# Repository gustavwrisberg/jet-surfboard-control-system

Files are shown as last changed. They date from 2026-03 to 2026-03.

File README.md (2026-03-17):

# Jet-Driven Surfboard Control System

## Project Overview
This project is a **jet-driven surfboard control system** inspired by commercial boards.  
It integrates embedded controllers, wireless communication, and a high-power propulsion system.

### Components Built
- **Controller:** ESP32-based throttle input with OLED display (SS495A Hall sensor)
- **Bridge:** ESP32 VESC bridge for UART communication to VESC and telemetry relay
- **VESC Motor Controller:** Off-the-shelf Makerbase VESC 84V 200A
- **Battery Pack:** Custom 10s5p Li-ion (Enpower INR21700-30SG)
- **Wireless Charging Pad:** For 3.7V cells powering the controller

> Most components are off-the-shelf to reduce cost and accelerate prototyping.  

---

## System Architecture

**Description:**
- Controller reads throttle from Hall sensor and displays telemetry on OLED.
- Throttle is sent to VESC bridge via ESP-NOW.
- VESC bridge communicates throttle to VESC via UART and relays telemetry back to controller.
- Battery supplies power to VESC and controller; wireless charger charges 3.7V cells for the controller.

---

### Wiring Diagram
Wiring Diagram

**Highlights:**
- Color-coded wires for clarity:
  - **Red:** Power lines
  - **Black:** Ground
  - **Blue:** Signal lines
  - **Green:** Communication (UART/ESP-NOW)
- Proper spacing to illustrate connections clearly between Controller, Bridge, VESC, Motor, and Battery.

---

## Build & Flash
Build & Flash Instructions
Install Arduino IDE or PlatformIO.
Install dependencies:
- Adafruit_SSD1306
- Adafruit_GFX
- ESP32 board definitions
Connect ESP32 to your PC.
run the read mac adress simulator, and write that into the code of the opposite controller.

Open controller.ino or bridge.ino.
Select the correct board (ESP32 Dev Module) and COM port.
Click Upload.

## Code Reference
### Controller (Throttle + OLED)
```cpp
// See src/controller.ino
#include <esp_now.h>
#include <WiFi.h>
#include <Wire.h>
#include <Adafruit_GFX.h>
#include <Adafruit_SSD1306.h>
// ... full controller code ...

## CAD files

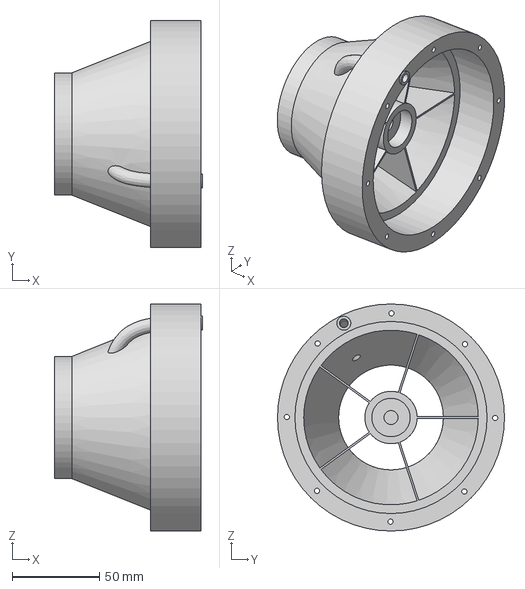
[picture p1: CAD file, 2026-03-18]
3dfiles/Nozzle.step
85.0 x 130.0 x 130.0 mm

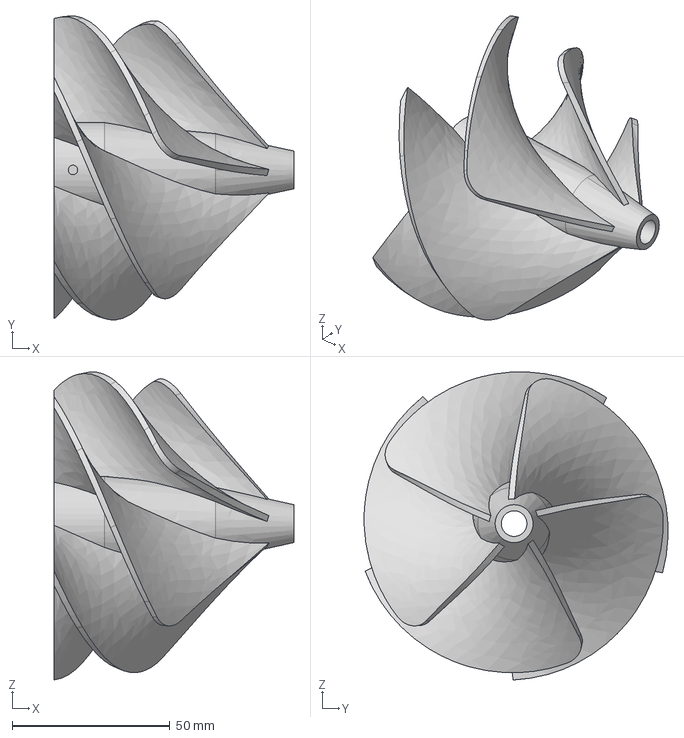
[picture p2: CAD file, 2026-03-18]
3dfiles/Impellar.step
76.0 x 96.3 x 97.6 mm

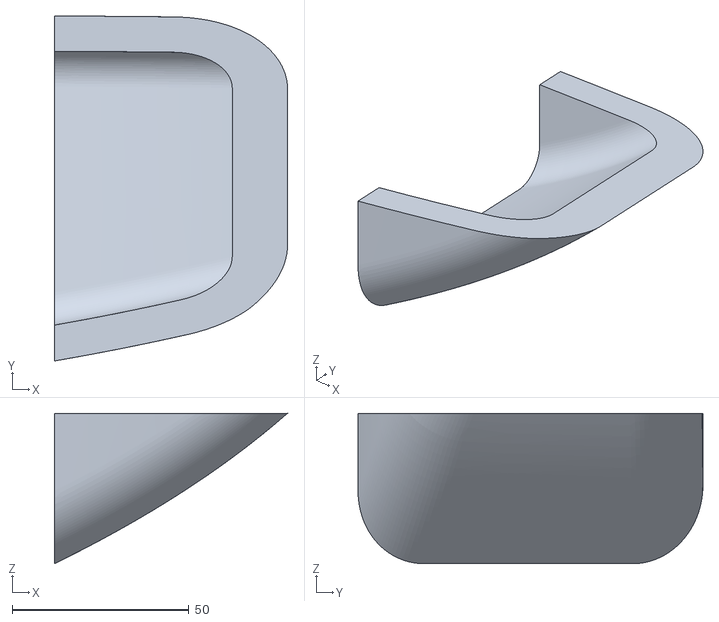
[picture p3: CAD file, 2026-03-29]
3dfiles/Surfboard/Surfboard.stl
66.0 x 97.7 x 42.6

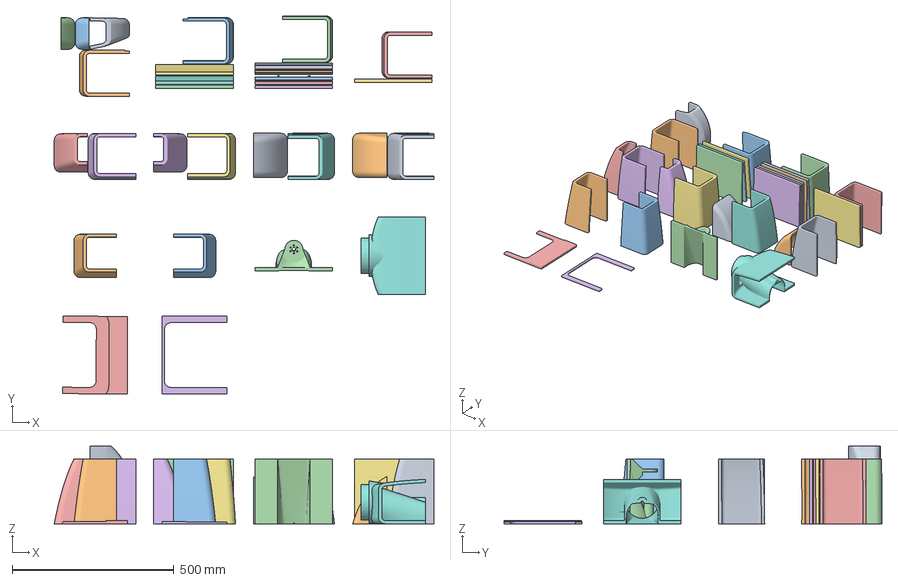
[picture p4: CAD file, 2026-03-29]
3dfiles/Surfboard/Surfboard bambu_lab.3mf
1173.8 x 1169.1 x 240.0 mm
Surfboard (9).stl
Surfboard (2).stl
Surfboard (2) (1).stl
Surfboard (7).stl
Surfboard (7) (1).stl
Surfboard (6) (1).stl
Surfboard (6).stl
Surfboard (5) (1).stl
Surfboard (5).stl
Surfboard (3) (1).stl
Surfboard (3).stl
Surfboard (5) (2).stl
Surfboard (1) (1).stl
Surfboard (1).stl
Surfboard (1) (2).stl
Surfboard (3) (2).stl
Surfboard (6) (3).stl
Surfboard (5) (3).stl
Surfboard (2) (2).stl
Surfboard (1) (3).stl
Surfboard (3) (3).stl
Surfboard (7) (3).stl
Surfboard (6) (2).stl
Surfboard (4) (2).stl
Surfboard (4) (1).stl
Surfboard (4).stl
Surfboard (8).stl
Surfboard.stl
Surfboard (7) (2).stl
Surfboard (2) (3).stl

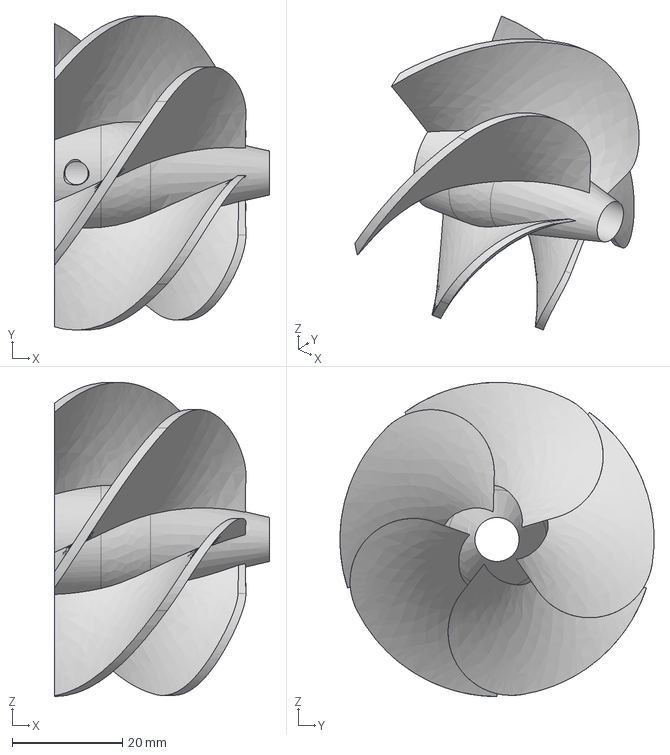
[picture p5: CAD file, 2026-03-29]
3dfiles/Surfboard/small_impellar.step
39.0 x 57.0 x 57.0 mm

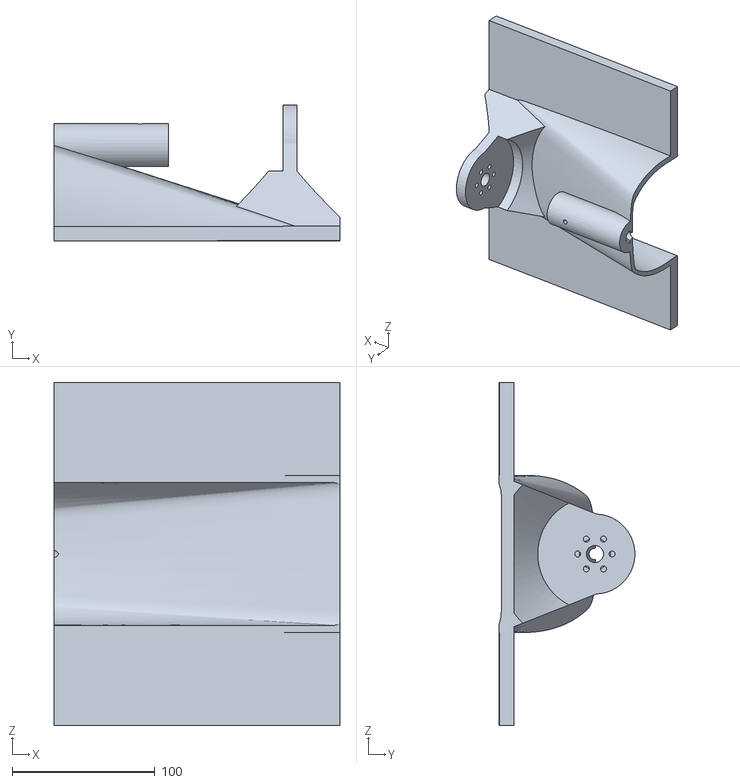
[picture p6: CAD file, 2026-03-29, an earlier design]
3dfiles/Surfboard/Surfboard (5) (2).stl
200.0 x 94.9 x 240.0

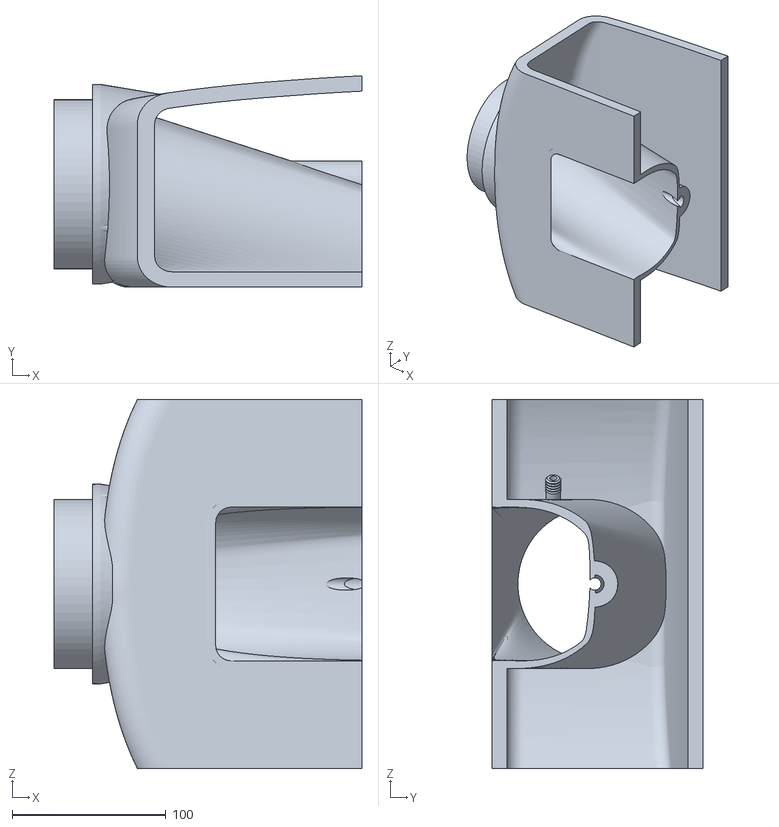
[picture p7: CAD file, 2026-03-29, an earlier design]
3dfiles/Surfboard/Surfboard (4) (2).stl
200.0 x 137.5 x 240.0

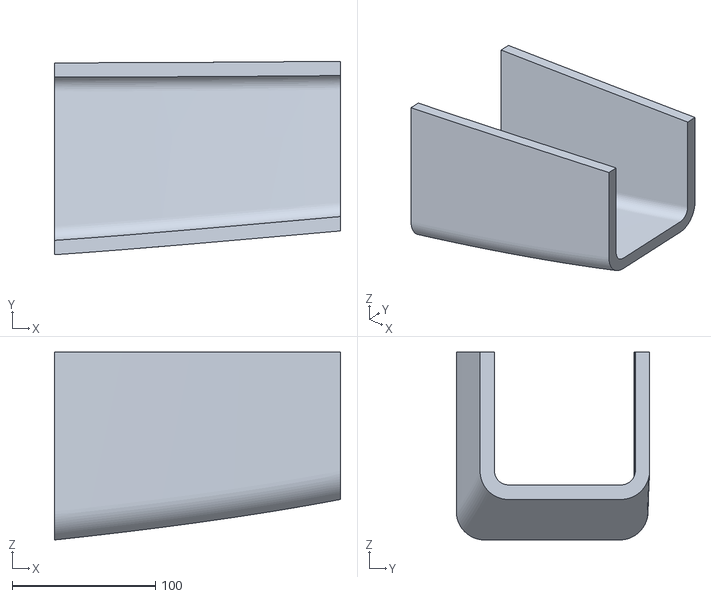
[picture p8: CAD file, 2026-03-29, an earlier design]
3dfiles/Surfboard/Surfboard (3).stl
200.0 x 135.3 x 131.5

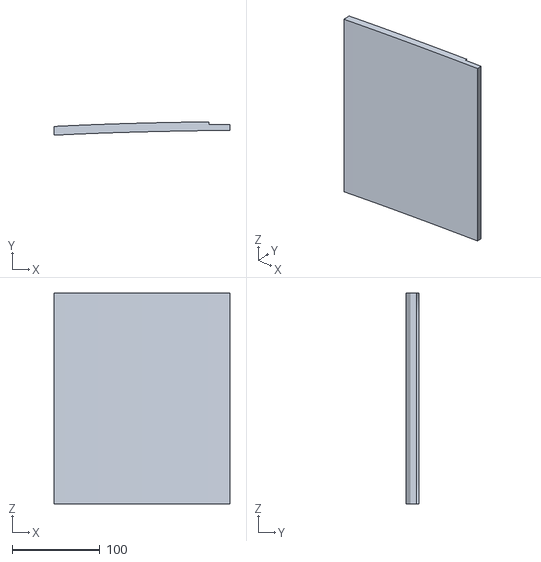
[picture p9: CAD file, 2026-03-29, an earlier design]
3dfiles/Surfboard/Surfboard (5) (3).stl
200.0 x 15.3 x 240.0

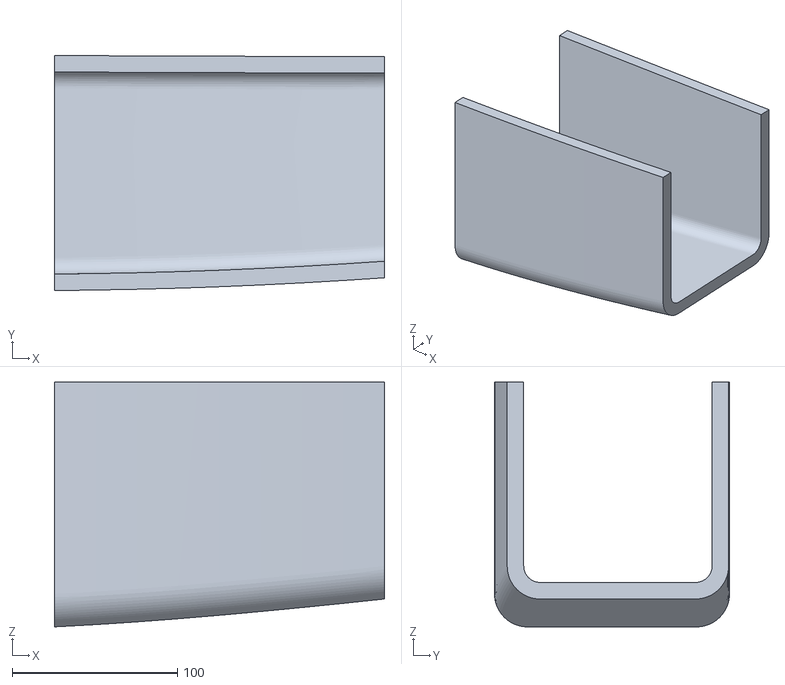
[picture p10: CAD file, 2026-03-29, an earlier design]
3dfiles/Surfboard/Surfboard (6).stl
200.0 x 142.5 x 148.4

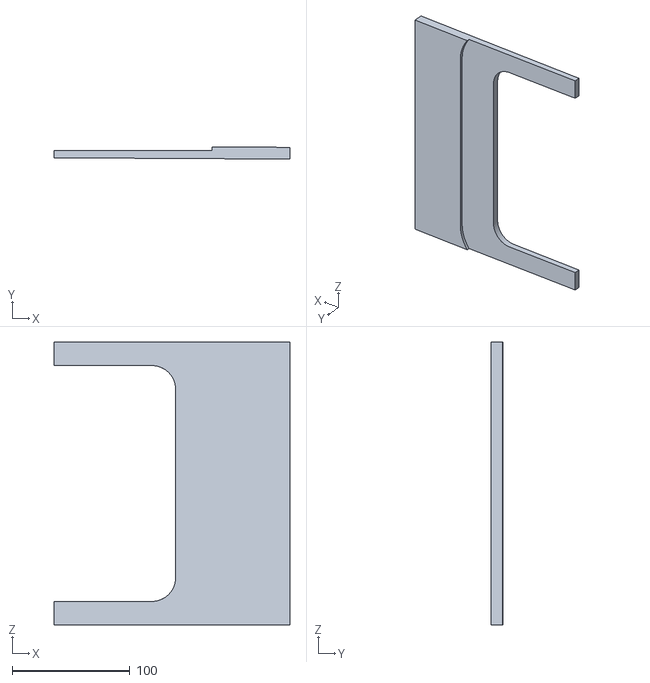
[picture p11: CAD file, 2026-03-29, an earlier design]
3dfiles/Surfboard/Surfboard (7) (2).stl
200.0 x 10.4 x 240.0

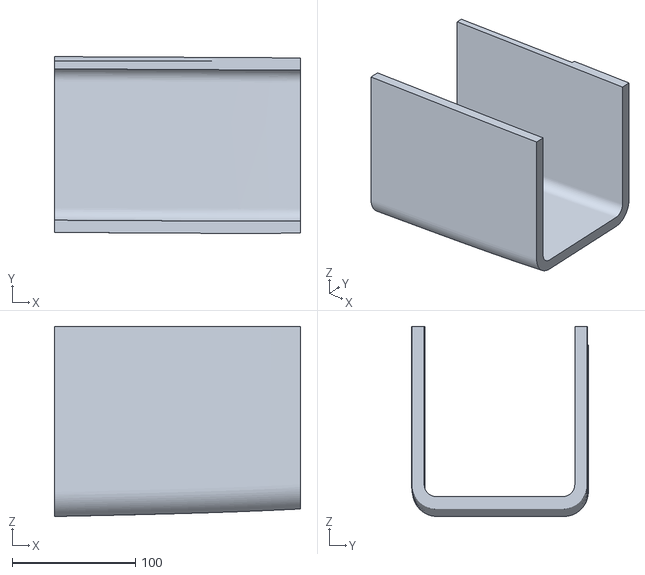
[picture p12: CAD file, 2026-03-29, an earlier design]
3dfiles/Surfboard/Surfboard (7).stl
200.0 x 143.7 x 154.5

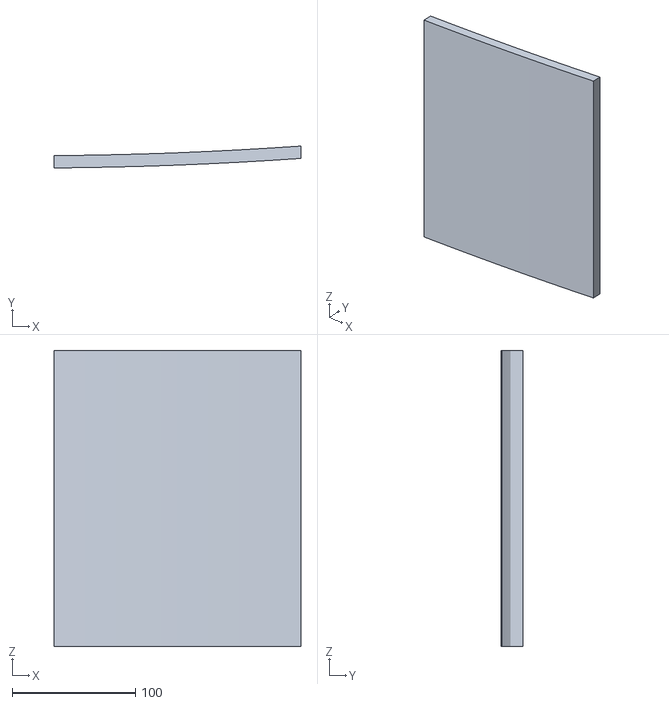
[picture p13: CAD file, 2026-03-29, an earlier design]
3dfiles/Surfboard/Surfboard (6) (3).stl
200.0 x 17.7 x 240.0

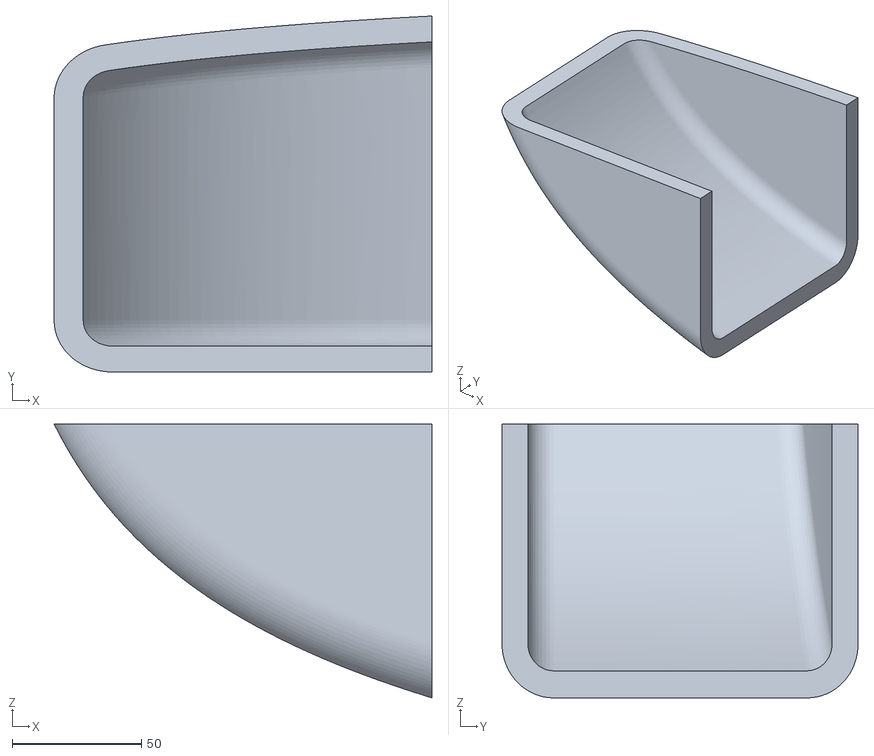
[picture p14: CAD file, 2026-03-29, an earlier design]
3dfiles/Surfboard/Surfboard (4).stl
146.0 x 137.5 x 105.8

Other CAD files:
3dfiles/Surfboard/Surfboard (8).stl
3dfiles/Surfboard/Surfboard (9).stl
3dfiles/Surfboard/Surfboard (5).stl
3dfiles/Surfboard/Surfboard (2) (2).stl
3dfiles/Surfboard/Surfboard (1) (1).stl
3dfiles/Surfboard/Surfboard (1) (2).stl
3dfiles/Surfboard/Surfboard (1) (3).stl
3dfiles/Surfboard/Surfboard (1).stl
3dfiles/Surfboard/Surfboard (2) (1).stl
3dfiles/Surfboard/Surfboard (2) (3).stl
3dfiles/Surfboard/Surfboard (2).stl
3dfiles/Surfboard/Surfboard (3) (1).stl
3dfiles/Surfboard/Surfboard (3) (2).stl
3dfiles/Surfboard/Surfboard (3) (3).stl
3dfiles/Surfboard/Surfboard (4) (1).stl
3dfiles/Surfboard/Surfboard (5) (1).stl
3dfiles/Surfboard/Surfboard (6) (1).stl
3dfiles/Surfboard/Surfboard (6) (2).stl
3dfiles/Surfboard/Surfboard (7) (1).stl
3dfiles/Surfboard/Surfboard (7) (3).stl

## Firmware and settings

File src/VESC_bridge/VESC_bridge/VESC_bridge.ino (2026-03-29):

// ---------- ESP32 Bridge : ESP-NOW <-> VESC UART ----------
#include <esp_now.h>
#include <WiFi.h>
#include <VescUart.h>

// ---------- VESC UART ----------
// Change these if your wiring is different
#define VESC_RX_PIN 16   // ESP32 RX  <- VESC TX
#define VESC_TX_PIN 17   // ESP32 TX  -> VESC RX
#define VESC_BAUD   115200

HardwareSerial VESCSerial(2);
VescUart UART;

// ---------- Control tuning ----------
const float MAX_DUTY = 0.35f;               // 0.0 .. 1.0, tune carefully
const uint32_t RX_TIMEOUT_MS = 500;         // failsafe if no throttle packets
const uint32_t TELEMETRY_PERIOD_MS = 100;   // send telemetry at 10 Hz
const uint32_t KEEPALIVE_PERIOD_MS = 100;   // VESC keepalive
const float THROTTLE_DEADBAND_PCT = 0.5f;

// ---------- Packet formats ----------
struct ThrottlePacket {
  uint32_t seq;
  float throttle_pct;   // 0..100
};

struct TelemetryPacket {
  uint32_t seq_echo;
  bool failsafe;
  float throttle_echo;
  float rpm;
  float voltage_v;
  float motor_current_a;
  float tempMotor;
  float watt_hours;
  uint32_t age_ms;
};

// ---------- Globals ----------
volatile ThrottlePacket gThrottle = {};
volatile bool gHaveThrottle = false;
volatile uint32_t gLastRxMillis = 0;

uint8_t controllerMac[6] = {0};
bool controllerKnown = false;
bool peerAdded = false;

uint32_t lastTelemetryTx = 0;
uint32_t lastKeepalive = 0;

// ---------- Helpers ----------
static inline float clampf(float v, float lo, float hi) {
  return v < lo ? lo : (v > hi ? hi : v);
}

void rememberControllerPeer(const uint8_t *mac) {
  memcpy(controllerMac, mac, 6);
  controllerKnown = true;

  if (peerAdded) {
    esp_now_del_peer(controllerMac);
    peerAdded = false;
  }

  esp_now_peer_info_t peer = {};
  memcpy(peer.peer_addr, mac, 6);
  peer.channel = 0;
  peer.encrypt = false;

  if (esp_now_add_peer(&peer) == ESP_OK) {
    peerAdded = true;
  }
}

float throttlePctToDuty(float throttlePct) {
  float pct = clampf(throttlePct, 0.0f, 100.0f);

  if (pct < THROTTLE_DEADBAND_PCT) {
    return 0.0f;
  }

  pct = (pct - THROTTLE_DEADBAND_PCT) * 100.0f / (100.0f - THROTTLE_DEADBAND_PCT);
  pct = clampf(pct, 0.0f, 100.0f);

  return (pct / 100.0f) * MAX_DUTY;
}

// ---------- ESP-NOW callbacks ----------
// Newer ESP32 Arduino core callback signatures
void onSent(const wifi_tx_info_t *info, esp_now_send_status_t status) {
  (void)info;
  (void)status;
}

void onRecv(const esp_now_recv_info_t *recv_info, const uint8_t *data, int len) {
  if (len != sizeof(ThrottlePacket)) return;

  ThrottlePacket pkt;
  memcpy(&pkt, data, sizeof(pkt));

  memcpy((void*)&gThrottle, &pkt, sizeof(pkt));
  gHaveThrottle = true;
  gLastRxMillis = millis();

  if (recv_info && recv_info->src_addr) {
    rememberControllerPeer(recv_info->src_addr);
  }
}

void sendTelemetry(bool failsafeActive, float throttleEcho) {
  if (!controllerKnown || !peerAdded) return;

  TelemetryPacket t = {};
  ThrottlePacket rxCopy;

  noInterrupts();
  memcpy(&rxCopy, (const void*)&gThrottle, sizeof(rxCopy));
  interrupts();

  t.seq_echo = rxCopy.seq;
  t.failsafe = failsafeActive;
  t.throttle_echo = throttleEcho;
  t.age_ms = millis() - gLastRxMillis;

  if (UART.getVescValues()) {
    t.rpm = UART.data.rpm;
    t.voltage_v = UART.data.inpVoltage;
    t.motor_current_a = UART.data.avgMotorCurrent;
    t.tempMotor = UART.data.tempMotor;
    t.watt_hours = UART.data.wattHours;
  } else {
    t.rpm = 0.0f;
    t.voltage_v = 0.0f;
    t.motor_current_a = 0.0f;
    t.tempMotor = 0.0f;
    t.watt_hours = 0.0f;
  }

  esp_now_send(controllerMac, (uint8_t*)&t, sizeof(t));
}

// ---------- Setup ----------
void setup() {
  Serial.begin(115200);
  delay(500);

  // VESC UART
  VESCSerial.begin(VESC_BAUD, SERIAL_8N1, VESC_RX_PIN, VESC_TX_PIN);
  UART.setSerialPort(&VESCSerial);

  // WiFi / ESP-NOW
  WiFi.mode(WIFI_STA);
  WiFi.disconnect();

  if (esp_now_init() != ESP_OK) {
    Serial.println("ESP-NOW init failed");
    while (true) delay(1000);
  }

  esp_now_register_send_cb(onSent);
  esp_now_register_recv_cb(onRecv);

  Serial.println("Bridge ready");
}

// ---------- Loop ----------
void loop() {
  ThrottlePacket rxCopy = {};
  bool haveThrottle = false;
  uint32_t lastRx = 0;

  noInterrupts();
  memcpy(&rxCopy, (const void*)&gThrottle, sizeof(rxCopy));
  haveThrottle = gHaveThrottle;
  lastRx = gLastRxMillis;
  interrupts();

  bool failsafeActive = (!haveThrottle) || ((millis() - lastRx) > RX_TIMEOUT_MS);

  float commandedThrottlePct = failsafeActive ? 0.0f : clampf(rxCopy.throttle_pct, 0.0f, 100.0f);
  float dutyCmd = throttlePctToDuty(commandedThrottlePct);

  // Drive VESC
  if (failsafeActive) {
    UART.setDuty(0.0f);
  } else {
    UART.setDuty(dutyCmd);
  }

  // Keepalive
  if (millis() - lastKeepalive >= KEEPALIVE_PERIOD_MS) {
    UART.sendKeepalive();
    lastKeepalive = millis();
  }

  // Telemetry back to controller
  if (millis() - lastTelemetryTx >= TELEMETRY_PERIOD_MS) {
    sendTelemetry(failsafeActive, commandedThrottlePct);
    lastTelemetryTx = millis();
  }

  // Debug
  static uint32_t lastPrint = 0;
  if (millis() - lastPrint >= 250) {
    Serial.print("failsafe=");
    Serial.print(failsafeActive ? "YES" : "NO");
    Serial.print(" thr%=");
    Serial.print(commandedThrottlePct, 1);
    Serial.print(" duty=");
    Serial.println(dutyCmd, 3);
    lastPrint = millis();
  }

  delay(10);
}

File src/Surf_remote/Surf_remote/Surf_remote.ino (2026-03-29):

// ---------- ESP32-C3 : Controller + OLED ----------
#include <esp_now.h>
#include <WiFi.h>
#include <Wire.h>
#include <Adafruit_GFX.h>
#include <Adafruit_SSD1306.h>

// ---------- OLED ----------
#define SCREEN_WIDTH 128
#define SCREEN_HEIGHT 64
#define OLED_ADDR 0x3C
#define OLED_SDA 8
#define OLED_SCL 9

Adafruit_SSD1306 display(SCREEN_WIDTH, SCREEN_HEIGHT, &Wire, -1);

// ---------- ADC input (Hall sensor / throttle pot) ----------
const int THROTTLE_ADC_PIN = 0;

// Learned at startup
int adcZero = 0;

// Full throttle ADC value
// Your throttle goes from about 3500 (rest) down to 1900 (full)
const int ADC_FULL = 1900;

const float DEAD_BAND_PCT = 10.0f;
const float EMA_ALPHA = 0.25f;

// ---------- ESP-NOW peer (bridge MAC) ----------
uint8_t bridgeMac[] = { 0x20, 0x6E, 0xF1, 0x6A, 0x20, 0x54 };

// ---------- Packet formats ----------
struct ThrottlePacket {
  uint32_t seq;
  float throttle_pct;
};

struct TelemetryPacket {
  uint32_t seq_echo;
  bool failsafe;
  float throttle_echo;
  float rpm;
  float voltage_v;
  float motor_current_a;
  float tempMotor;
  float watt_hours;
  uint32_t age_ms;
};

// ---------- Globals ----------
volatile TelemetryPacket gTelem = {};
uint32_t txSeq = 0;
uint32_t lastTelemMillis = 0;

// ---------- Warning thresholds ----------
#define TEMP_WARNING 80.0
#define VOLTAGE_LOW 12.0
#define BLINK_PERIOD 1000

// ---------- ESP-NOW callbacks ----------
void onSent(const wifi_tx_info_t *info, esp_now_send_status_t status) {
}

void onRecv(const esp_now_recv_info_t *recv_info, const uint8_t *data, int len) {
  if (len == sizeof(TelemetryPacket)) {
    memcpy((void*)&gTelem, data, sizeof(TelemetryPacket));
    lastTelemMillis = millis();
  }
}

// ---------- Helpers ----------
static inline float clampf(float v, float lo, float hi) {
  return v < lo ? lo : (v > hi ? hi : v);
}

float ema(float prev, float cur, float alpha) {
  return prev + alpha * (cur - prev);
}

bool blinkState() {
  return (millis() % BLINK_PERIOD) < (BLINK_PERIOD / 2);
}

int calibrateThrottleZero(int samples = 100) {
  long sum = 0;
  for (int i = 0; i < samples; i++) {
    sum += analogRead(THROTTLE_ADC_PIN);
    delay(5);
  }
  return sum / samples;
}

void drawOLED(float throttlePct, const TelemetryPacket& t, bool linkActive) {
  display.clearDisplay();
  display.setCursor(0, 0);
  display.setTextSize(1);
  display.setTextColor(SSD1306_WHITE);

  display.print("Link: ");
  if (!linkActive) {
    if (blinkState()) display.print("NO");
    else display.print("  ");
  } else {
    display.print("OK");
  }
  display.print(" FS: ");
  display.println(t.failsafe ? "YES" : "NO");

  display.print("Thr: ");
  display.print(throttlePct, 1);
  display.println("%");

  display.print("Spd: ");
  display.print(t.rpm, 0);
  display.println(" rpm");

  display.print("Volt: ");
  if (t.voltage_v > 0.01f && t.voltage_v < VOLTAGE_LOW && blinkState()) {
    display.println("!!");
  } else {
    display.print(t.voltage_v, 2);
    display.println(" V");
  }

  display.print("Curr: ");
  display.print(t.motor_current_a, 1);
  display.println(" A");

  display.print("Tmp: ");
  if (t.tempMotor > TEMP_WARNING && blinkState()) {
    display.print("!!");
  } else {
    display.print(t.tempMotor, 1);
    display.print("C");
  }
  display.print(" Wh:");
  display.print(t.watt_hours, 1);

  display.display();
}

// ---------- Setup ----------
void setup() {
  Serial.begin(115200);
  delay(500);

  Wire.begin(OLED_SDA, OLED_SCL);

  if (!display.begin(SSD1306_SWITCHCAPVCC, OLED_ADDR)) {
    Serial.println("SSD1306 init failed");
    while (true) delay(1000);
  }

  display.setRotation(2);

  display.clearDisplay();
  display.setTextSize(1);
  display.setTextColor(SSD1306_WHITE);
  display.setCursor(0, 0);
  display.println("OLED OK");
  display.display();
  delay(1000);

  analogReadResolution(12);
  analogSetAttenuation(ADC_11db);

  // Calibrate zero at startup
  adcZero = calibrateThrottleZero();

  Serial.print("adcZero = ");
  Serial.println(adcZero);

  WiFi.mode(WIFI_STA);

  if (esp_now_init() != ESP_OK) {
    Serial.println("ESP-NOW init failed");
    while (true) delay(1000);
  }

  esp_now_register_send_cb(onSent);
  esp_now_register_recv_cb(onRecv);

  esp_now_peer_info_t peer = {};
  memcpy(peer.peer_addr, bridgeMac, 6);
  peer.channel = 0;
  peer.encrypt = false;

  if (esp_now_add_peer(&peer) != ESP_OK) {
    Serial.println("Add peer failed");
    while (true) delay(1000);
  }
}

// ---------- Loop ----------
void loop() {
  static float filtAdc = 0;
  static uint32_t lastTx = 0;

  int raw = analogRead(THROTTLE_ADC_PIN);
  filtAdc = ema((filtAdc == 0) ? raw : filtAdc, raw, EMA_ALPHA);

  // Rest = adcZero, full = ADC_FULL
  // ADC decreases as throttle increases
  float pct = (adcZero - filtAdc) * 100.0f / (adcZero - ADC_FULL);
  pct = clampf(pct, 0.0f, 100.0f);

  if (pct < DEAD_BAND_PCT) {
    pct = 0.0f;
  }

  if (millis() - lastTx >= 50) {
    ThrottlePacket tx = {};
    tx.seq = ++txSeq;
    tx.throttle_pct = pct;
    esp_now_send(bridgeMac, (uint8_t*)&tx, sizeof(tx));
    lastTx = millis();
  }

  TelemetryPacket t;
  noInterrupts();
  memcpy(&t, (const void*)&gTelem, sizeof(TelemetryPacket));
  interrupts();

  bool linkActive = (millis() - lastTelemMillis) < 2000;

  Serial.print("raw=");
  Serial.print(raw);
  Serial.print(" zero=");
  Serial.print(adcZero);
  Serial.print(" pct=");
  Serial.println(pct, 1);

  drawOLED(pct, t, linkActive);

  delay(100);
}

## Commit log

2026-03-17 Added files for arduino controllers
2026-03-17 Create PlantUML wiring for controller
2026-03-17 Create plantuml jetboard wiring
2026-03-17 Create BOM
2026-03-17 Update BOM
2026-03-18 STEP files of board added
    [Impellar.step, Nozzle.step, Surfboard.step]
2026-03-29 step filer
    [Impellar.step, Nozzle.step, Surfboard (1) (1).stl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]
